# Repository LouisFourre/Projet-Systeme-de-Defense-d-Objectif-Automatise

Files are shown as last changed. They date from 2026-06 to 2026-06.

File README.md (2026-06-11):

# Projet-Systeme-de-Defense-d-Objectif-Automatise

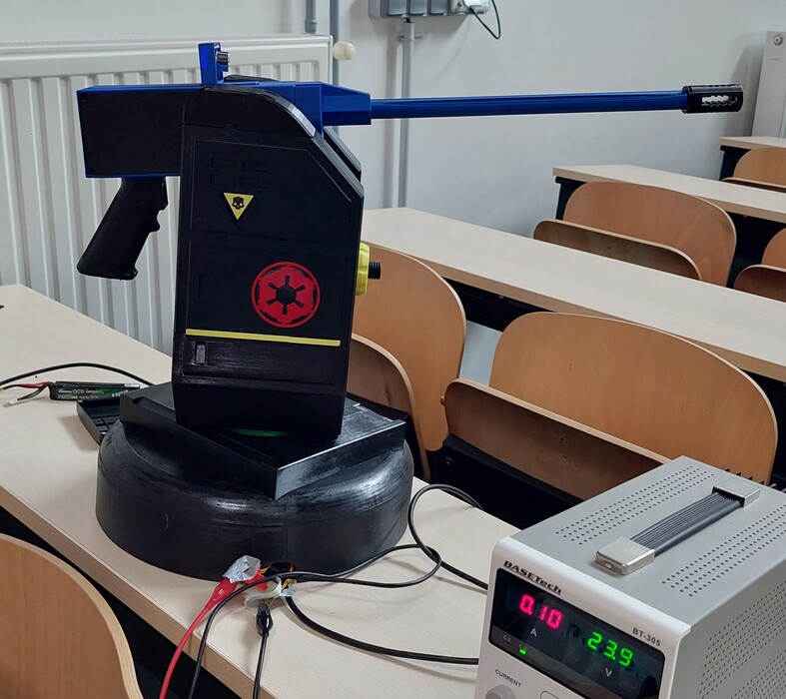
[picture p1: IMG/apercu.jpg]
Illustration


Conception d'une tourelle pouvant être contrôlée à distance par une manette ou complètement automatique via de la reconnaissance en direct de ballons de différentes couleurs grâce à une IA.

## Étapes

### Étape 1 : Éléments nécessaires

Vous aurez besoin d'imprimer les éléments nécessaires dans les quantités et matériaux indiqués sur la page 1.

Et vous aurer besoin d'acheter les objets présents sur la page 2.

https://docs.google.com/spreadsheets/d/1dJQVD0vWzvO0O84W56YvZOXAQwT8jr\_cPrxY0wQQ7l4/edit?usp=sharing

### Étape 2 : Réseau électronique

Soudez les composants sur une plaque de prototypage en suivant le schéma.

Le mosfet, son driver ainsi que condensateur doivent êtres sur une plaque séparée, installée dans la partie haute de la tourelle.



### Étape 3 : Assemblage

 **Assemblage de la base**

1. Insérez des inserts 3D correspondants dans tous les trous nécessaires.
2. Assemblez le roulement de la tourelle en mettant des billes de 6mm entre les deux parties (forcez la partie haute sur la partie basse pour clipser les deux parties).
3. Vissez le moteur avec le support moteur horizontal. 
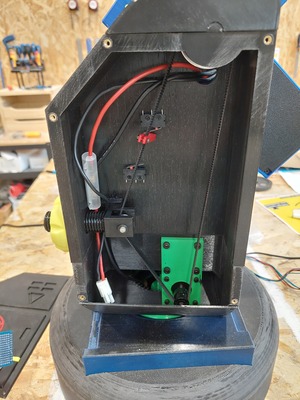
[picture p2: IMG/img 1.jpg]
  
4. Vissez le roulement de la tourelle sur la base N°1.
5. Vissez le&nbsp;support moteur horizontal sur le roulement de la tourelle en mettant la base du piedestal entre les deux.
6. Posez l'assemblage sur le piedestal.
7. Vissez le second moteur sur la base N°1 grace au support moteur d'élévation.
8. Collez les bases N°2 et N°3 sur le haut base N°1.
9. Assemblez le tendeur, puis insérez le dans le trou dans la base N°2. 
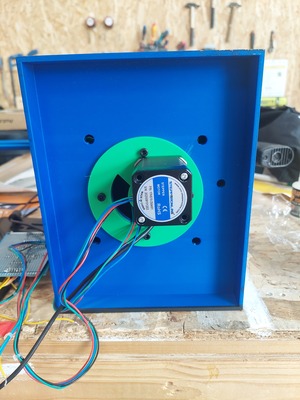
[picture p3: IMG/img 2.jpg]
  

**Assemblage de la partie de tir**

1. Insérez les inserts 3d M3 et M2.5 dans les différents endroits.
2. Fixez les arbres a brides avec des vis M3x6.
3. Insérez la gearbox dans son support et sécurisez la avec 2 vis et ecrous M5 dans les trous en bas du support.
4. Alignez le cache haut avec les trous sur la partie haute du support et vissez avec des vis m3x50 afin de sécuriser le cache et la gearbox.
5. Coupez les axes a 85mm, inserez les dans les arbres a bride pui sécurisez els avec 4 vis m2.
6. Insérer le mag latch et le ressort dans la partie prévue a cette effet. Refermer avec le cache prévu.
7. Vissez le canon 3d sur sa base ainsi que le cache flamme au bout.
8. Inserer le canon airsoft dans le nozzle.
9. Faire glisser l'assemblage du canon sur le support gearbox, securiser avec une vis m3x50.
10. Mettre les caches cotes de la gearbox avec des vis m2.5x5
11. Mettre les roulements a billes et l'engrennage sur les arbres a brides (engrennage sur le coté gauche).

**Assemblage&nbsp;**

1. Poser la partie de tir sur la base.
2. Passer la courroie dans les 2 engrennages, puis la tendre en tournant le tendeur dans le sens horaire.
3. Passer les cables en laissant un peu de mous, passer le cable pour la caméra usb.
4. Sécuriser avec les connecteurs haut et 8 vis m5x30
5. Poser du mieux que possible la plaque avec le mosfet.
6. Brancher la batterie.
7. Poser les caches.
8. Enjoy!





### Étape 4 : Utilisation

Vous aurez besoin d'un ordinateur capable de faire tourner un modèle d'IA en local ainsi que 2 ports USB disponibles (voir un troisième si votre manette n'as pas de bluetooth).

Le programme "" doit être installé sur le raspberry pico afin de pouvoir controller les moteurs, l'alimentation du pico se fait via l'ordinateur grâce au cable USB.

Vous devez connecter le&nbsp;raspberry pico a l'ordinateur ainsi que la webcam, puis brancher l'alimentation en 24v 2a sur les cables des moteurs.

Le programme principal contient tout le nécessaire pour utiliser la tourelle, les commandes sont les suivantes:

- Joystick de gauche: déplacer la tourelle

- Gachette droite : tirer

- Bouton croix : changer de caméra (nécessaire dans les cas ou votre ordinateur possède une caméra, le programme peut ne pas sélectionner la bonne caméra au démarrage)

## Fichiers CAD

Assemblage_tourelle.stl

## Machines utilisées

Bambu Lab H2S, Anycubic Kobra S1

## Matériaux utilisés

PLA, PETG

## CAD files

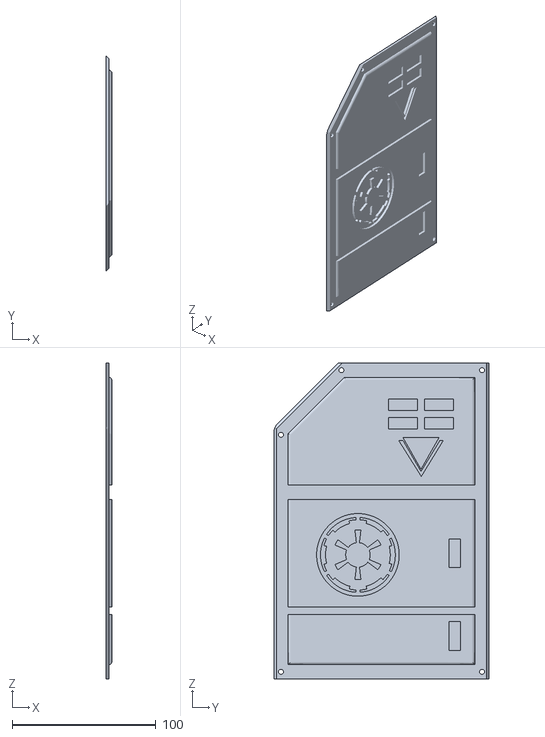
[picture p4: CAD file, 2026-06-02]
CAO/Fichier individuels/Base/Plaque haut gauche.stl
4.00 x 150.0 x 220.0

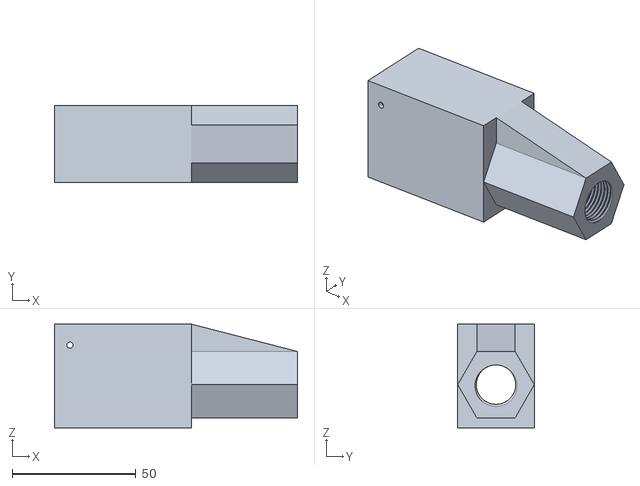
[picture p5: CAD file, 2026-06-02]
CAO/Fichier individuels/Canon/Base.stl
98.4 x 31.0 x 42.0

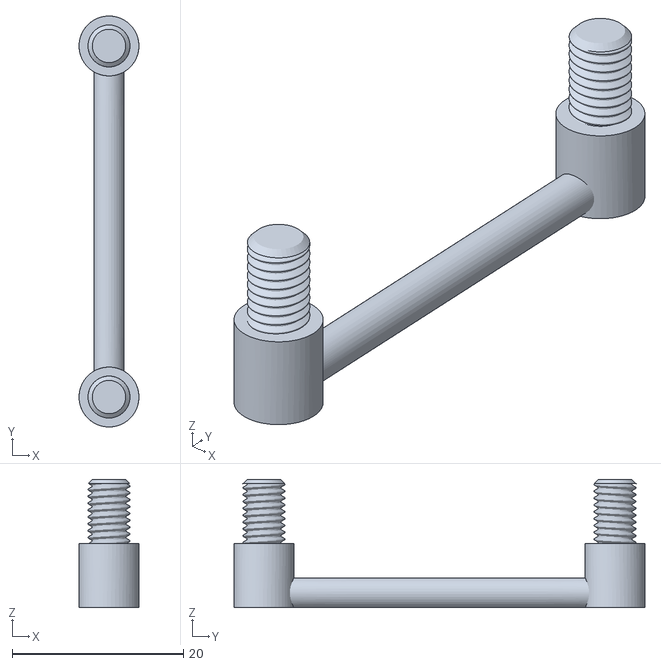
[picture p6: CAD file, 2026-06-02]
CAO/Fichier individuels/Chargeur/Attache chargeur.stl
7.00 x 48.0 x 15.0

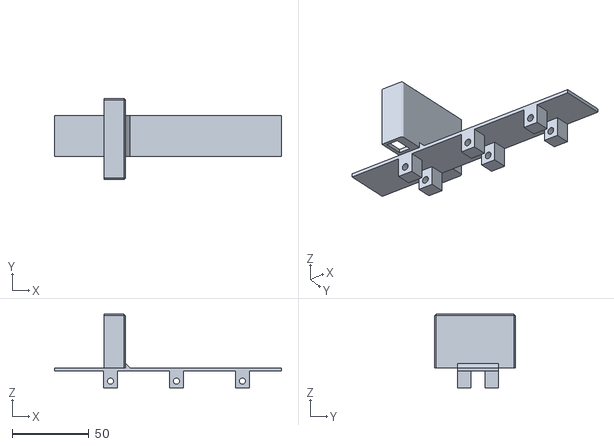
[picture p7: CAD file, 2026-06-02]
CAO/Fichier individuels/Gearbox/Cache haut.stl
148.0 x 53.0 x 48.0

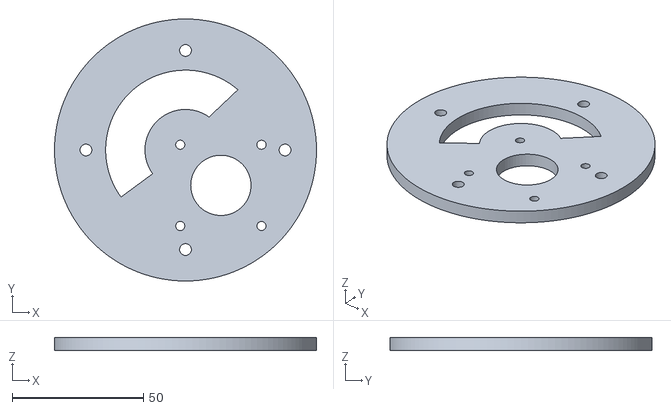
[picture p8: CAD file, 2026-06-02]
CAO/Fichier individuels/Piedestal/Support moteur.stl
100.0 x 100.0 x 5.00

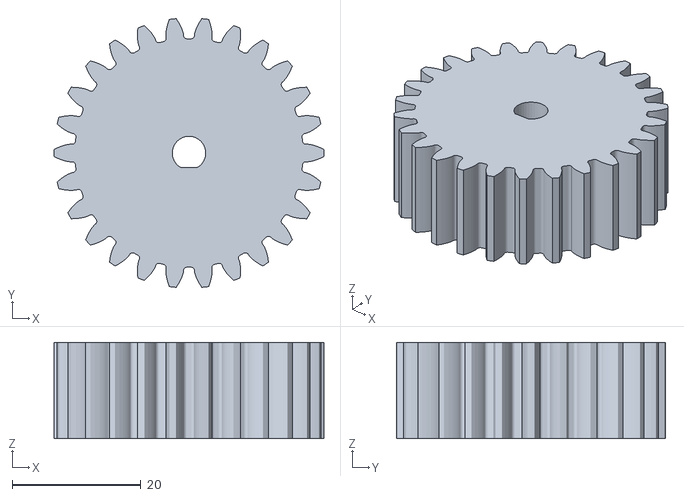
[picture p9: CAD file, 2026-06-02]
CAO/Fichier individuels/Ring/Inner gear.stl
42.0 x 41.8 x 15.0

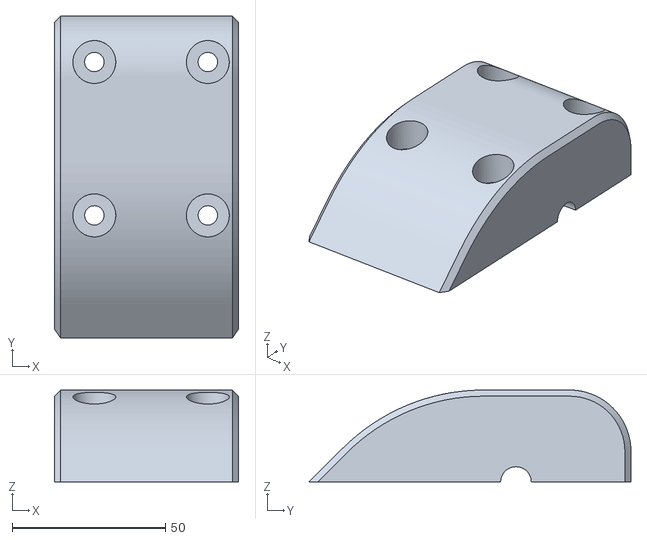
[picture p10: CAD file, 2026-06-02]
CAO/Fichier individuels/Base/Connecteur haut.stl
60.0 x 105.0 x 30.0

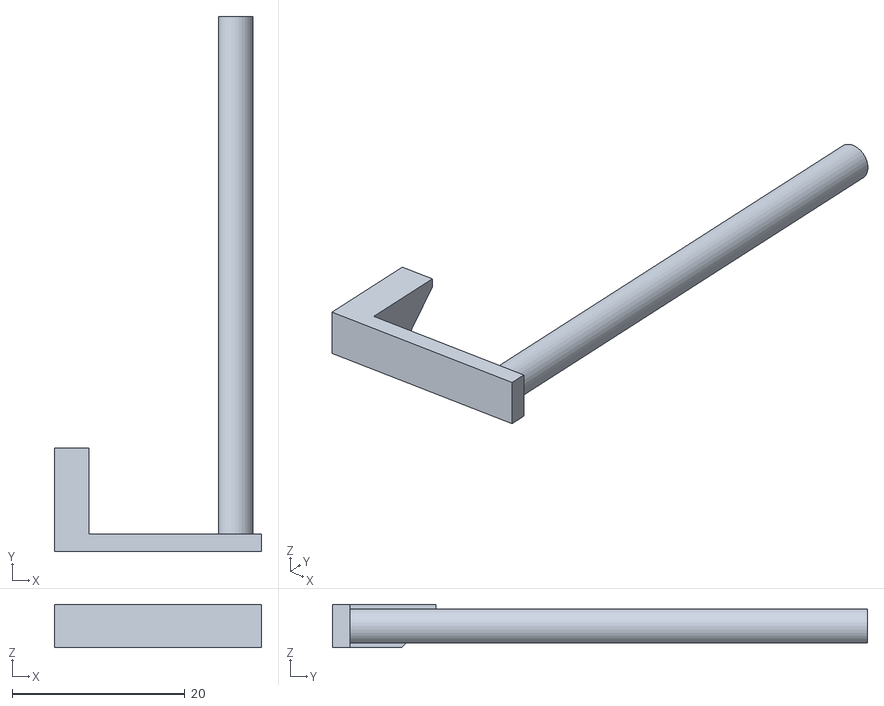
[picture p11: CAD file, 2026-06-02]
CAO/Fichier individuels/Chargeur/Mag latch.stl
24.0 x 62.0 x 5.00

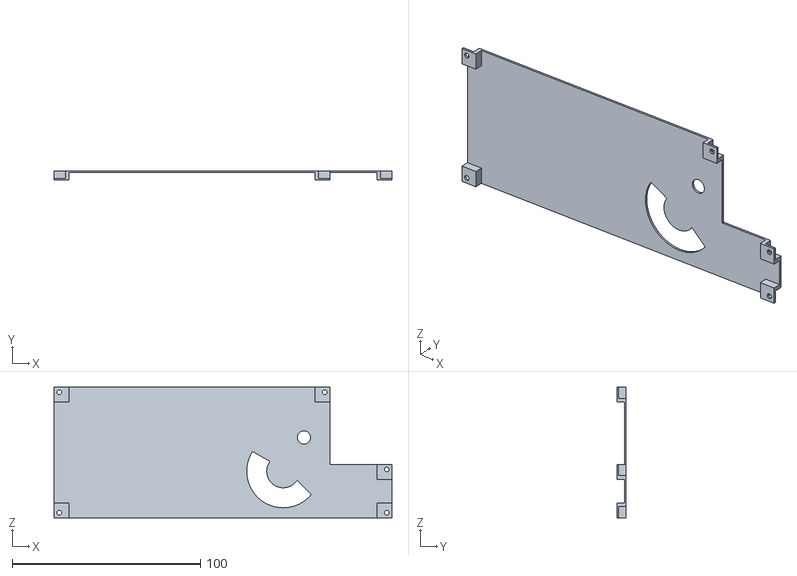
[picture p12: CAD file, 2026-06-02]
CAO/Fichier individuels/Gearbox/Cache gearbox coté gauche.stl
179.5 x 5.00 x 69.5

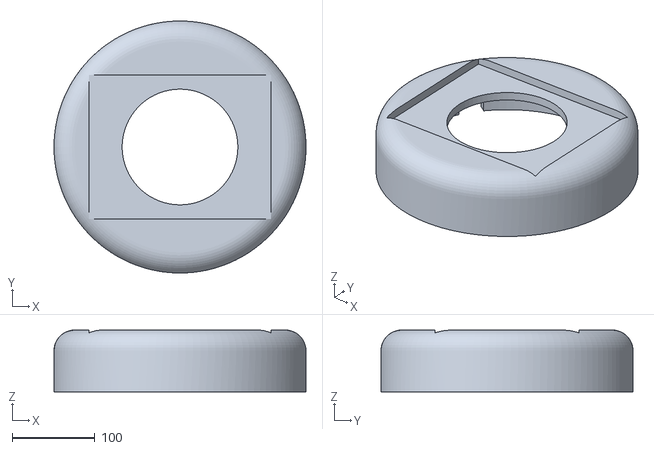
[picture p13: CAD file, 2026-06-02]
CAO/Fichier individuels/Piedestal/socle.stl
305.0 x 305.0 x 75.0

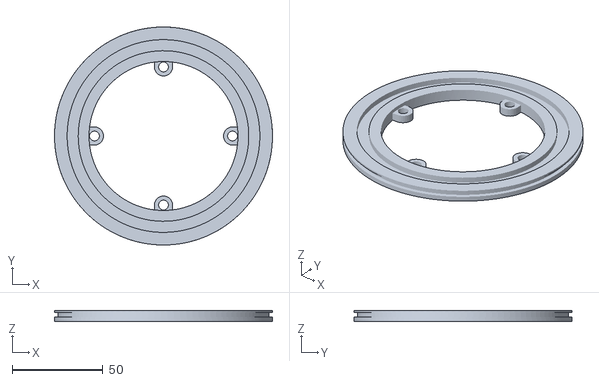
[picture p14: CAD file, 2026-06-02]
CAO/Fichier individuels/Ring/Lower ring.stl
120.0 x 120.0 x 6.00

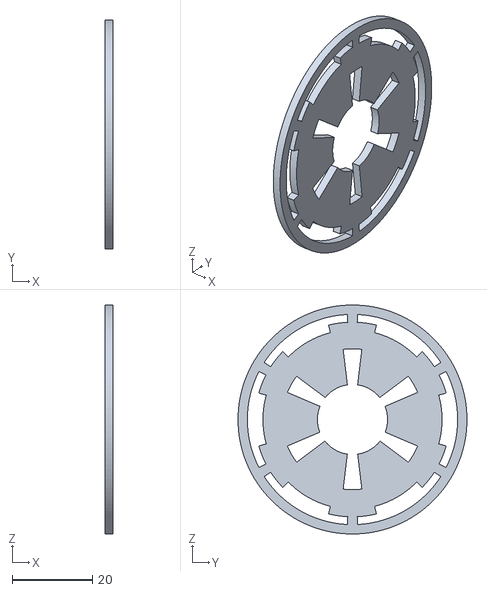
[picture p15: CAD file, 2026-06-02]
CAO/Fichier individuels/Base/Insert star wars.stl
2.00 x 57.2 x 57.2

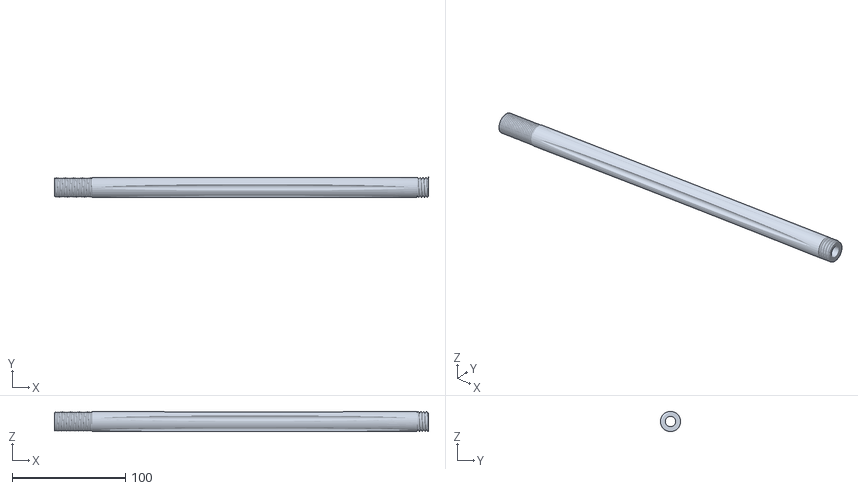
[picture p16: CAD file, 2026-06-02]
CAO/Fichier individuels/Canon/Canon.stl
329.8 x 17.8 x 17.8

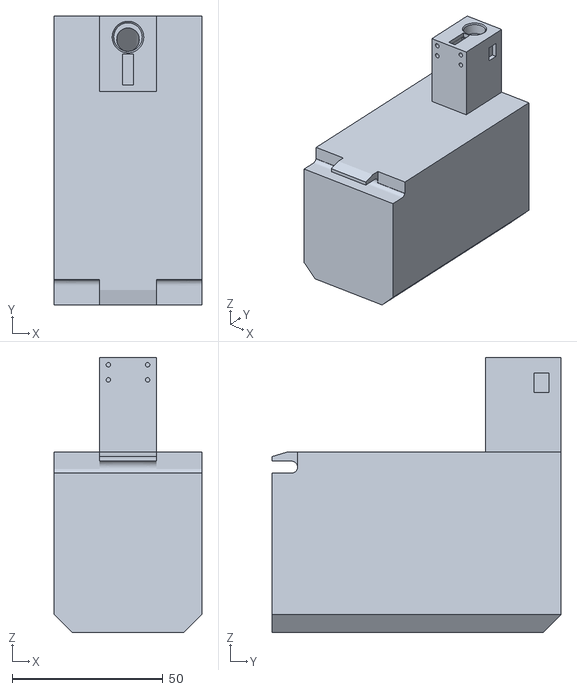
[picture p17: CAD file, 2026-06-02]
CAO/Fichier individuels/Chargeur/Chargeur.stl
49.0 x 96.0 x 91.5

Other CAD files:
CAO/Fichier individuels/Gearbox/Cache gearbox coté droit.stl
CAO/Fichier individuels/Piedestal/base.stl
CAO/Fichier individuels/Ring/Upper ring.stl
CAO/Fichier individuels/Base/Support moteur elevation.stl
CAO/Fichier individuels/Base/Base (1).stl
CAO/Fichier individuels/Base/Base (2).stl
CAO/Fichier individuels/Base/Base.stl
CAO/Fichier individuels/Base/Connecteur haut (1).stl
CAO/Fichier individuels/Base/Insert bas.stl
CAO/Fichier individuels/Base/Insert hd2.stl
CAO/Fichier individuels/Base/Plaque bas gauche.stl
CAO/Fichier individuels/Base/extension capteur fin de course.stl
CAO/Fichier individuels/Base/insert hd2 bas.stl
CAO/Fichier individuels/Base/tendeur.stl
CAO/Fichier individuels/Canon/Frein de bouche (1).stl
CAO/Fichier individuels/Canon/Frein de bouche.stl
CAO/Fichier individuels/Gearbox/Support gearbox.stl
CAO/Fichier individuels/Piedestal/Couvercle base.stl

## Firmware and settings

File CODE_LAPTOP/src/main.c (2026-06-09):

#include <SDL3/SDL.h>
#include <stdbool.h>
#include <stdint.h>
#include <stdio.h>
#include <stdlib.h>
#include <string.h>

#ifdef _WIN32
#include <windows.h>
#endif

#define YOLO_ENABLED 1
#define YOLO_PYTHON_EXE "python"
#define YOLO_MODEL_PATH "best.pt"
#define YOLO_WORKER_SCRIPT "src\\yolo_worker.py"
#define YOLO_INPUT_SIZE 320
#define YOLO_CONFIDENCE 0.90f
#define YOLO_FRAME_INTERVAL_MS 33
#define YOLO_MAX_DETECTIONS 1

#define CAMERA_TARGET_WIDTH 1920
#define CAMERA_TARGET_HEIGHT 1080
#define CAMERA_TARGET_FPS 60

#define AIM_POINT_X_RATIO (1.0f / 1.82f)
#define AIM_POINT_Y_RATIO (1.0f / 2.40f)

#define AUTO_AIM_ENABLED 1
#define AUTO_AIM_CENTER_ZONE_RATIO 0.80f
#define AUTO_AIM_MAX_OUTPUT_PERCENT 45.0f
#define AUTO_AIM_INVERT_X 0
#define AUTO_AIM_INVERT_Y 0

#define AUTO_AIM_X_KP 70.0f
#define AUTO_AIM_X_KI 0.0f
#define AUTO_AIM_X_KD 8.0f
#define AUTO_AIM_Y_KP 70.0f
#define AUTO_AIM_Y_KI 0.0f
#define AUTO_AIM_Y_KD 8.0f

static int clamp_int(int value, int min_value, int max_value);

typedef struct
{
    int class_id;
    float confidence;
    float x[4];
    float y[4];
} YoloDetection;

typedef struct
{
    int has_detection;
    int model_ready;
    int frame_width;
    int frame_height;
    YoloDetection detection;
} YoloSnapshot;

typedef struct
{
    float kp;
    float ki;
    float kd;
    float integral;
    float previous_error;
    int has_previous_error;
    Uint64 previous_ticks_ms;
} PidController;

typedef struct
{
    PidController x;
    PidController y;
    int active_last_frame;
} AutoAimState;

#ifdef _WIN32
typedef struct
{
    HANDLE process;
    HANDLE stdin_write;
    HANDLE stdout_read;
    SDL_Thread *thread;
    SDL_Mutex *mutex;
    SDL_Condition *condition;
    unsigned char *pending_frame;
    size_t pending_capacity;
    size_t pending_size;
    int pending_width;
    int pending_height;
    int has_pending;
    int stop;
    int enabled;
    YoloDetection detections[YOLO_MAX_DETECTIONS];
    int detection_count;
    int frame_width;
    int frame_height;
    int model_ready;
    char status[160];
} YoloWorker;

static void yolo_worker_set_status(YoloWorker *worker, const char *status)
{
    if (!worker || !worker->mutex)
    {
        return;
    }

    SDL_LockMutex(worker->mutex);
    snprintf(worker->status, sizeof(worker->status), "%s", status);
    SDL_UnlockMutex(worker->mutex);
}

static int write_exact(HANDLE handle, const void *data, size_t size)
{
    const unsigned char *bytes = (const unsigned char *)data;

    while (size > 0)
    {
        DWORD chunk = size > (size_t)(1024 * 1024) ? (DWORD)(1024 * 1024) : (DWORD)size;
        DWORD written = 0;

        if (!WriteFile(handle, bytes, chunk, &written, NULL) || written == 0)
        {
            return 0;
        }

        bytes += written;
        size -= written;
    }

    return 1;
}

static int read_protocol_line(HANDLE handle, char *buffer, size_t capacity)
{
    size_t used = 0;

    if (capacity == 0)
    {
        return 0;
    }

    while (used + 1 < capacity)
    {
        char c = '\0';
        DWORD read = 0;

        if (!ReadFile(handle, &c, 1, &read, NULL) || read == 0)
        {
            return 0;
        }

        if (c == '\n')
        {
            break;
        }

        if (c != '\r')
        {
            buffer[used++] = c;
        }
    }

    buffer[used] = '\0';
    return 1;
}

static int yolo_worker_thread(void *data)
{
    YoloWorker *worker = (YoloWorker *)data;
    unsigned char *local_frame = NULL;
    size_t local_capacity = 0;

    for (;;)
    {
        int width = 0;
        int height = 0;
        size_t frame_size = 0;

        SDL_LockMutex(worker->mutex);
        while (!worker->has_pending && !worker->stop)
        {
            SDL_WaitCondition(worker->condition, worker->mutex);
        }

        if (worker->stop)
        {
            SDL_UnlockMutex(worker->mutex);
            break;
        }

        width = worker->pending_width;
        height = worker->pending_height;
        frame_size = worker->pending_size;

        if (frame_size > local_capacity)
        {
            unsigned char *resized = (unsigned char *)realloc(local_frame, frame_size);
            if (!resized)
            {
                worker->has_pending = 0;
                snprintf(worker->status, sizeof(worker->status), "YOLO: allocation frame impossible");
                SDL_UnlockMutex(worker->mutex);
                continue;
            }

            local_frame = resized;
            local_capacity = frame_size;
        }

        memcpy(local_frame, worker->pending_frame, frame_size);
        worker->has_pending = 0;
        SDL_UnlockMutex(worker->mutex);

        uint32_t header[3] = {(uint32_t)width, (uint32_t)height, (uint32_t)frame_size};
        if (!write_exact(worker->stdin_write, header, sizeof(header)) ||
            !write_exact(worker->stdin_write, local_frame, frame_size))
        {
            yolo_worker_set_status(worker, "YOLO: ecriture vers le worker echouee");
            break;
        }

        char line[512];
        if (!read_protocol_line(worker->stdout_read, line, sizeof(line)))
        {
            yolo_worker_set_status(worker, "YOLO: worker arrete");
            break;
        }

        int reported_count = atoi(line);
        int detection_count = clamp_int(reported_count, 0, YOLO_MAX_DETECTIONS);
        YoloDetection detections[YOLO_MAX_DETECTIONS];
        memset(detections, 0, sizeof(detections));

        for (int i = 0; i < reported_count; ++i)
        {
            if (!read_protocol_line(worker->stdout_read, line, sizeof(line)))
            {
                yolo_worker_set_status(worker, "YOLO: lecture resultats echouee");
                reported_count = i;
                detection_count = clamp_int(reported_count, 0, YOLO_MAX_DETECTIONS);
                break;
            }

            if (i >= YOLO_MAX_DETECTIONS)
            {
                continue;
            }

            YoloDetection detection;
            memset(&detection, 0, sizeof(detection));
            int parsed = sscanf(line, "%d %f %f %f %f %f %f %f %f %f",
                                &detection.class_id,
                                &detection.confidence,
                                &detection.x[0], &detection.y[0],
                                &detection.x[1], &detection.y[1],
                                &detection.x[2], &detection.y[2],
                                &detection.x[3], &detection.y[3]);
            if (parsed == 10)
            {
                detections[i] = detection;
            }
        }

        SDL_LockMutex(worker->mutex);
        memcpy(worker->detections, detections, sizeof(detections));
        worker->detection_count = detection_count;
        worker->frame_width = width;
        worker->frame_height = height;
        worker->model_ready = 1;
        snprintf(worker->status, sizeof(worker->status), "YOLO: %d detection(s), input %d", detection_count, YOLO_INPUT_SIZE);
        SDL_UnlockMutex(worker->mutex);
    }

    free(local_frame);
    return 0;
}

static int yolo_worker_start(YoloWorker *worker)
{
    memset(worker, 0, sizeof(*worker));
    snprintf(worker->status, sizeof(worker->status), "YOLO: inactif");

    if (!YOLO_ENABLED)
    {
        return 0;
    }

    worker->mutex = SDL_CreateMutex();
    worker->condition = SDL_CreateCondition();
    if (!worker->mutex || !worker->condition)
    {
        fprintf(stderr, "YOLO: mutex/condition impossible: %s\n", SDL_GetError());
        return 0;
    }

    SECURITY_ATTRIBUTES security_attributes;
    memset(&security_attributes, 0, sizeof(security_attributes));
    security_attributes.nLength = sizeof(security_attributes);
    security_attributes.bInheritHandle = TRUE;

    HANDLE stdin_read = NULL;
    HANDLE stdout_write = NULL;

    if (!CreatePipe(&stdin_read, &worker->stdin_write, &security_attributes, 0) ||
        !CreatePipe(&worker->stdout_read, &stdout_write, &security_attributes, 0))
    {
        fprintf(stderr, "YOLO: creation des pipes impossible: %lu\n", GetLastError());
        if (stdin_read)
            CloseHandle(stdin_read);
        if (stdout_write)
            CloseHandle(stdout_write);
        return 0;
    }

    SetHandleInformation(worker->stdin_write, HANDLE_FLAG_INHERIT, 0);
    SetHandleInformation(worker->stdout_read, HANDLE_FLAG_INHERIT, 0);

    char command_line[512];
    snprintf(command_line, sizeof(command_line),
             "\"%s\" -u \"%s\" --model \"%s\" --imgsz %d --conf %.3f",
             YOLO_PYTHON_EXE, YOLO_WORKER_SCRIPT, YOLO_MODEL_PATH, YOLO_INPUT_SIZE, YOLO_CONFIDENCE);

    STARTUPINFOA startup_info;
    PROCESS_INFORMATION process_info;
    memset(&startup_info, 0, sizeof(startup_info));
    memset(&process_info, 0, sizeof(process_info));
    startup_info.cb = sizeof(startup_info);
    startup_info.dwFlags = STARTF_USESTDHANDLES;
    startup_info.hStdInput = stdin_read;
    startup_info.hStdOutput = stdout_write;
    startup_info.hStdError = GetStdHandle(STD_ERROR_HANDLE);

    if (!CreateProcessA(NULL, command_line, NULL, NULL, TRUE, CREATE_NO_WINDOW, NULL, NULL, &startup_info, &process_info))
    {
        fprintf(stderr, "YOLO: impossible de lancer le worker Python: %lu\n", GetLastError());
        CloseHandle(stdin_read);
        CloseHandle(stdout_write);
        CloseHandle(worker->stdin_write);
        CloseHandle(worker->stdout_read);
        worker->stdin_write = NULL;
        worker->stdout_read = NULL;
        return 0;
    }

    CloseHandle(stdin_read);
    CloseHandle(stdout_write);
    CloseHandle(process_info.hThread);
    worker->process = process_info.hProcess;

    worker->thread = SDL_CreateThread(yolo_worker_thread, "yolo-worker", worker);
    if (!worker->thread)
    {
        fprintf(stderr, "YOLO: impossible de creer le thread: %s\n", SDL_GetError());
        TerminateProcess(worker->process, 1);
        CloseHandle(worker->process);
        CloseHandle(worker->stdin_write);
        CloseHandle(worker->stdout_read);
        worker->process = NULL;
        worker->stdin_write = NULL;
        worker->stdout_read = NULL;
        return 0;
    }

    worker->enabled = 1;
    snprintf(worker->status, sizeof(worker->status), "YOLO: chargement de %s", YOLO_MODEL_PATH);
    return 1;
}

static void yolo_worker_stop(YoloWorker *worker)
{
    if (!worker)
    {
        return;
    }

    if (worker->mutex)
    {
        SDL_LockMutex(worker->mutex);
        worker->stop = 1;
        if (worker->condition)
        {
            SDL_SignalCondition(worker->condition);
        }
        SDL_UnlockMutex(worker->mutex);
    }

    if (worker->stdin_write)
    {
        CloseHandle(worker->stdin_write);
        worker->stdin_write = NULL;
    }

    if (worker->process)
    {
        TerminateProcess(worker->process, 0);
    }

    if (worker->thread)
    {
        SDL_WaitThread(worker->thread, NULL);
        worker->thread = NULL;
    }

    if (worker->stdout_read)
    {
        CloseHandle(worker->stdout_read);
        worker->stdout_read = NULL;
    }

    if (worker->process)
    {
        CloseHandle(worker->process);
        worker->process = NULL;
    }

    free(worker->pending_frame);
    worker->pending_frame = NULL;
    worker->pending_capacity = 0;

    if (worker->condition)
    {
        SDL_DestroyCondition(worker->condition);
        worker->condition = NULL;
    }

    if (worker->mutex)
    {
        SDL_DestroyMutex(worker->mutex);
        worker->mutex = NULL;
    }
}

static int yolo_submit_surface(YoloWorker *worker, SDL_Surface *surface)
{
    if (!worker || !worker->enabled || !surface)
    {
        return 0;
    }

    SDL_LockMutex(worker->mutex);
    if (worker->has_pending || worker->stop)
    {
        SDL_UnlockMutex(worker->mutex);
        return 0;
    }
    SDL_UnlockMutex(worker->mutex);

    SDL_Surface *rgb = SDL_ConvertSurface(surface, SDL_PIXELFORMAT_RGB24);
    if (!rgb)
    {
        return 0;
    }

    const int row_bytes = rgb->w * 3;
    const size_t frame_size = (size_t)row_bytes * (size_t)rgb->h;
    int accepted = 0;

    SDL_LockMutex(worker->mutex);
    if (!worker->has_pending)
    {
        if (frame_size > worker->pending_capacity)
        {
            unsigned char *resized = (unsigned char *)realloc(worker->pending_frame, frame_size);
            if (resized)
            {
                worker->pending_frame = resized;
                worker->pending_capacity = frame_size;
            }
        }

        if (frame_size <= worker->pending_capacity)
        {
            const unsigned char *source = (const unsigned char *)rgb->pixels;
            for (int y = 0; y < rgb->h; ++y)
            {
                memcpy(worker->pending_frame + (size_t)y * (size_t)row_bytes,
                       source + (size_t)y * (size_t)rgb->pitch,
                       (size_t)row_bytes);
            }

            worker->pending_size = frame_size;
            worker->pending_width = rgb->w;
            worker->pending_height = rgb->h;
            worker->has_pending = 1;
            accepted = 1;
            SDL_SignalCondition(worker->condition);
        }
    }
    SDL_UnlockMutex(worker->mutex);

    SDL_DestroySurface(rgb);
    return accepted;
}
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
int main(int argc, char *argv[])
{
    (void)argc;
    (void)argv;

    if (!SDL_Init(SDL_INIT_VIDEO | SDL_INIT_CAMERA | SDL_INIT_GAMEPAD))
    {
        fprintf(stderr, "SDL_Init failed: %s\n", SDL_GetError());
        return 1;
    }

    SDL_Window *window = SDL_CreateWindow("S.A.D.O Controller", 800, 600, SDL_WINDOW_RESIZABLE);
    if (!window)
    {
        fprintf(stderr, "SDL_CreateWindow failed: %s\n", SDL_GetError());
        SDL_Quit();
        return 1;
    }

    SDL_Renderer *renderer = SDL_CreateRenderer(window, NULL);
    if (!renderer)
    {
        fprintf(stderr, "SDL_CreateRenderer failed: %s\n", SDL_GetError());
        SDL_DestroyWindow(window);
        SDL_Quit();
        return 1;
    }

    int camera_count = 0;
    SDL_CameraID *cameras = SDL_GetCameras(&camera_count);

    if (!cameras || camera_count <= 0)
    {
        fprintf(stderr, "Aucune webcam detectee: %s\n", SDL_GetError());
        SDL_DestroyRenderer(renderer);
        SDL_DestroyWindow(window);
        SDL_Quit();
        return 1;
    }

    int cam_index = 0;
    SDL_Camera *camera = open_camera_low_latency(cameras[cam_index], cam_index);
    if (!camera)
    {
        fprintf(stderr, "SDL_OpenCamera failed: %s\n", SDL_GetError());
        SDL_DestroyRenderer(renderer);
        SDL_DestroyWindow(window);
        SDL_Quit();
        return 1;
    }

    SDL_Gamepad *gamepad = NULL;
    int gamepad_count = 0;
    SDL_JoystickID *gamepads = SDL_GetGamepads(&gamepad_count);
    if (gamepads && gamepad_count > 0)
    {
        gamepad = SDL_OpenGamepad(gamepads[0]);
    }
    SDL_free(gamepads);

    if (!gamepad)
    {
        fprintf(stderr, "Aucune manette detectee ou ouverture impossible: %s\n", SDL_GetError());
    }

#ifdef _WIN32
    SerialPort serial_port = {INVALID_HANDLE_VALUE};
    int serial_ready = serial_open(&serial_port, "\\\\.\\COM6", CBR_115200);
    char last_command[64] = "";

    if (!serial_ready)
    {
        fprintf(stderr, "Impossible d'ouvrir COM6: %lu\n", GetLastError());
    }
#else
    int serial_ready = 0;
#endif

    YoloWorker yolo_worker;
    yolo_worker_start(&yolo_worker);
    AutoAimState auto_aim;
    auto_aim_init(&auto_aim);

    SDL_Texture *camera_texture = NULL;
    SDL_Event event;
    int running = 1;
    int rt_was_pressed = 0;
    Uint64 last_yolo_submit_ms = 0;

    Uint64 last_fire_ms = 0;
    int auto_aim_active = 0;
    int auto_aim_aligned = 0;
    int auto_turn_percent = 0;
    int auto_throttle_percent = 0;

    while (running)
    {
        while (SDL_PollEvent(&event))
        {
            if (event.type == SDL_EVENT_QUIT)
            {
                running = 0;
            }
        }

        if (gamepad && SDL_GetGamepadButton(gamepad, SDL_GAMEPAD_BUTTON_NORTH))
        {
            // change camera
            cam_index = (cam_index + 1) % camera_count;
            SDL_CloseCamera(camera);
            camera = open_camera_low_latency(cameras[cam_index], cam_index);
            if (!camera)
            {
                fprintf(stderr, "ERROR WHILE OPENING CAMERA %d: %s\n", cam_index, SDL_GetError());
            }
            else
            {
                fprintf(stderr, "Switched to camera %d\n", cam_index);
            }
            SDL_Delay(10);
        }

        SDL_UpdateJoysticks();

        if (!gamepad)
        {
            int refreshed_count = 0;
            SDL_JoystickID *refreshed_gamepads = SDL_GetGamepads(&refreshed_count);
            if (refreshed_gamepads && refreshed_count > 0)
            {
                gamepad = SDL_OpenGamepad(refreshed_gamepads[0]);
            }
            SDL_free(refreshed_gamepads);
        }

        Uint64 timestamp = 0;
        Uint64 latest_timestamp = 0;
        SDL_Surface *latest_frame = NULL;
        SDL_Surface *frame = NULL;

        while (camera && (frame = SDL_AcquireCameraFrame(camera, &timestamp)) != NULL)
        {
            if (latest_frame)
            {
                SDL_ReleaseCameraFrame(camera, latest_frame);
            }

            latest_frame = frame;
            latest_timestamp = timestamp;
        }

        if (latest_frame)
        {
            SDL_Texture *new_texture = SDL_CreateTextureFromSurface(renderer, latest_frame);

            const Uint64 now_ms = SDL_GetTicks();
            if (now_ms - last_yolo_submit_ms >= YOLO_FRAME_INTERVAL_MS)
            {
                if (yolo_submit_surface(&yolo_worker, latest_frame))
                {
                    last_yolo_submit_ms = now_ms;
                }
            }

            SDL_ReleaseCameraFrame(camera, latest_frame);
            (void)latest_timestamp;

            if (new_texture)
            {
                if (camera_texture)
                {
                    SDL_DestroyTexture(camera_texture);
                }

                camera_texture = new_texture;
            }
        }

        Sint16 left_x_raw = 0;
        Sint16 left_y_raw = 0;
        Sint16 rt_raw = 0;

        int fire = false;

        if (gamepad)
        {
            left_x_raw = SDL_GetGamepadAxis(gamepad, SDL_GAMEPAD_AXIS_LEFTX);
            left_y_raw = SDL_GetGamepadAxis(gamepad, SDL_GAMEPAD_AXIS_LEFTY);
            rt_raw = SDL_GetGamepadAxis(gamepad, SDL_GAMEPAD_AXIS_RIGHT_TRIGGER);

            const int rt_pressed = rt_raw > 12000;
            if (rt_pressed && !rt_was_pressed)
            {
                SDL_RumbleGamepad(gamepad, 0xFFFF, 0xFFFF, 100);
                SDL_RumbleGamepadTriggers(gamepad, 0x3000, 0xC000, 120);
            }
            rt_was_pressed = rt_pressed;
            Uint64 now_ms = SDL_GetTicks();
            if (rt_pressed && now_ms - last_fire_ms >= 800)
            {
                fire = true;
            }
        }
        else
        {
            rt_was_pressed = 0;
        }

        YoloSnapshot yolo_snapshot;
        yolo_get_snapshot(&yolo_worker, &yolo_snapshot);
        auto_turn_percent = 0;
        auto_throttle_percent = 0;
        auto_aim_aligned = 0;
        auto_aim_active = auto_aim_compute(&auto_aim,
                                           &yolo_snapshot,
                                           &auto_turn_percent,
                                           &auto_throttle_percent,
                                           &auto_aim_aligned);

        if (serial_ready && (gamepad || auto_aim_active))
        {
            int throttle = axis_to_percent(left_y_raw);
            int turn = axis_to_percent(left_x_raw);

            if (auto_aim_active)
            {
                turn = auto_turn_percent;
                throttle = auto_throttle_percent;
            }

            int left_motor = auto_aim_active ? clamp_int(turn, -100, 100) : clamp_int((int)(turn * 0.5f), -100, 100);
            int right_motor = clamp_int(throttle, -100, 100);
            int dir1 = left_motor >= 0 ? 1 : 0;
            int dir2 = right_motor >= 0 ? 1 : 0;
            int delay1 = axis_to_motor_delay_us(left_motor);
            int delay2 = axis_to_motor_delay_us(right_motor);
            char command[64];

            if (fire)
            {
                last_fire_ms = SDL_GetTicks();
                printf("FIRE!");
            }

            snprintf(command, sizeof(command), "%d,%d,%d,%d,%d\n", dir1, delay1, dir2, delay2, fire ? 1 : 0);

            if (strcmp(command, last_command) != 0)
            {
                printf("Sending command: %s", command);

                if (!serial_write_line(&serial_port, command))
                {
                    fprintf(stderr, "Ecriture serie echouee sur COM6\n");
                    serial_ready = 0;
                }
                else
                {
                    strcpy(last_command, command);
                }
            }
        }

        SDL_SetRenderDrawColor(renderer, 0, 0, 0, 255);
        SDL_RenderClear(renderer);

        if (camera_texture)
        {
            SDL_RenderTexture(renderer, camera_texture, NULL, NULL);
        }

        int window_width = 0;
        int window_height = 0;
        SDL_GetWindowSize(window, &window_width, &window_height);

        draw_yolo_detections(renderer, &yolo_worker, window_width, window_height);

        char yolo_status[160];
        yolo_copy_status(&yolo_worker, yolo_status, sizeof(yolo_status));
        SDL_SetRenderDrawColor(renderer, 0, 0, 0, 255);
        SDL_RenderDebugTextFormat(renderer, 9.0f, 9.0f, "%s", yolo_status);
        SDL_SetRenderDrawColor(renderer, 180, 255, 180, 255);
        SDL_RenderDebugTextFormat(renderer, 8.0f, 8.0f, "%s", yolo_status);
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

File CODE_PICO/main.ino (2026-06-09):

#include <Arduino.h>
#include <stdio.h>

// Broches pour le premier driver (moteur 1)
const int PIN_EN = 8;   // GP8  -> EN (enable) du TMC2209 (actif LOW)
const int PIN_STEP = 9; // GP9  -> STEP du TMC2209 (impulsion pour avancer d'un pas)
const int PIN_DIR = 10; // GP10 -> DIR du TMC2209 (sens de rotation)

// Broches pour le second driver (moteur 2)
const int PIN_EN2 = 18;   // GP18 -> EN TMC2209 (actif LOW)
const int PIN_STEP2 = 19; // GP19 -> STEP TMC2209
const int PIN_DIR2 = 20;  // GP20 -> DIR TMC2209

// TIR
const int PIN_TIR = 15;

int motor1Dir = HIGH;
int motor1Delay = 0;
int motor2Dir = HIGH;
int motor2Delay = 0;
bool fireCommand = false;
unsigned long motor1NextStepUs = 0;
unsigned long motor2NextStepUs = 0;

// -------------------- Fonction de déplacement --------------------
// moveNEMA : génère les impulsions STEP pour deux moteurs en parallèle.
// Paramètres :
//  - steps  : nombre d'impulsions (pas) à effectuer pour le moteur 1
//  - delayUs: délai en microsecondes entre les changements d'état de STEP (vitesse moteur 1)
//  - dir    : sens de rotation pour le moteur 1 (HIGH/LOW)
//  - steps2 : nombre d'impulsions pour le moteur 2
//  - delayUs2: délai en microsecondes entre les changements d'état de STEP (vitesse moteur 2)
//  - dir2   : sens de rotation pour le moteur 2 (HIGH/LOW)
// Remarque : dans la fonction actuelle, on utilise `delayUs` pour les deux moteurs
// au moment d'appeler depuis `loop()` (voir commentaire sur le parsing série).
void moveNEMA(int steps, int delayUs, bool dir, int steps2, int delayUs2, bool dir2)
{
    digitalWrite(PIN_DIR, dir);
    digitalWrite(PIN_DIR2, dir2);

    for (int i = 0; i < steps || i < steps2; i++)
    {
        if (i < steps)
        {
            digitalWrite(PIN_STEP, HIGH);
        }
        if (i < steps2)
        {
            digitalWrite(PIN_STEP2, HIGH);
        }

        delayMicroseconds(delayUs);

        if (i < steps)
        {
            digitalWrite(PIN_STEP, LOW);
        }
        if (i < steps2)
        {
            digitalWrite(PIN_STEP2, LOW);
        }

        delayMicroseconds(delayUs);
    }
}

void updateMotor(int stepPin, int dirPin, int dir, int delayUs, unsigned long &nextStepUs)
{
    if (delayUs <= 0)
    {
        digitalWrite(stepPin, LOW);
        return;
    }

    digitalWrite(dirPin, dir ? HIGH : LOW);

    unsigned long now = micros();
    if ((long)(now - nextStepUs) >= 0)
    {
        digitalWrite(stepPin, HIGH);
        delayMicroseconds(2);
        digitalWrite(stepPin, LOW);
        nextStepUs = now + (unsigned long)delayUs;
    }
}

void processFireCommand(bool fire)
{
    if (!fire)
    {
        return;
    }
    digitalWrite(PIN_TIR, HIGH);
    delay(65);
    digitalWrite(PIN_TIR, LOW);
    Serial.write("Fire");
}

void parseCommand(const String &input)
{
    int dir1 = 0;
    int delay1 = 0;
    int dir2 = 0;
    int delay2 = 0;
    int fire_command = 0;

    if (sscanf(input.c_str(), "%d,%d,%d,%d,%d", &dir1, &delay1, &dir2, &delay2, &fire_command) == 5)
    {
        motor1Dir = dir1;
        motor1Delay = delay1;
        motor2Dir = dir2;
        motor2Delay = delay2;
        fireCommand = fire_command != false;

        if (motor1Delay <= 0)
        {
            digitalWrite(PIN_STEP, LOW);
        }
        if (motor2Delay <= 0)
        {
            digitalWrite(PIN_STEP2, LOW);
        }
    }
}

void setup()
{
    pinMode(PIN_EN, OUTPUT);
    pinMode(PIN_STEP, OUTPUT);
    pinMode(PIN_DIR, OUTPUT);
    pinMode(PIN_EN2, OUTPUT);
    pinMode(PIN_STEP2, OUTPUT);
    pinMode(PIN_DIR2, OUTPUT);
    pinMode(PIN_TIR, OUTPUT);

    digitalWrite(PIN_STEP, LOW);
    digitalWrite(PIN_STEP2, LOW);

    digitalWrite(PIN_DIR, HIGH);
    digitalWrite(PIN_DIR2, HIGH);

    digitalWrite(PIN_EN, LOW);
    digitalWrite(PIN_EN2, LOW);

    Serial.begin(115200);
    Serial.println("Démarrage...");

    delay(500);
}

void loop()
{
    if (Serial.available() > 0)
    {
        String input = Serial.readStringUntil('\n');
        parseCommand(input);
    }

    processFireCommand(fireCommand);
    updateMotor(PIN_STEP, PIN_DIR, motor1Dir, motor1Delay * 4, motor1NextStepUs);
    updateMotor(PIN_STEP2, PIN_DIR2, motor2Dir, motor2Delay * 4, motor2NextStepUs);
}

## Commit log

2026-06-02 ADD: CAO
    [Attache chargeur.stl, Base (1).stl, Base (2).stl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]
2026-06-09 Initialize Arduino sketch for dual motor control
